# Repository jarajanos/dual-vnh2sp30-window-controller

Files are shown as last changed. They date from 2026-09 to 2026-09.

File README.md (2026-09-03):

# Window Controller — ESP32-C3 + Monster Moto Shield VNH2SP30

ESP-IDF firmware for controlling two motorized greenhouse windows. Each motor
supports one-button operation, MQTT commands, current monitoring, automatic
end-stop detection, and a movement timeout.

## Requirements

- ESP-IDF v6.x
- Target: `esp32c3`

## Build and flash

```bash
idf.py set-target esp32c3
idf.py menuconfig          # Optional; sdkconfig.defaults provides the defaults
idf.py build
idf.py -p /dev/ttyUSB0 flash monitor
```

## Configuration

Create your local configuration from the tracked template, then set at least
the Wi-Fi and MQTT credentials:

```bash
cp main/config.example.h main/config.h
```

Edit `main/config.h`:

```c
#define WIFI_SSID        "YourNetwork"
#define WIFI_PASSWORD    "YourPassword"
#define MQTT_BROKER_URI  "mqtt://192.168.1.100:1883"
```

GPIO mapping and shared defaults are configured in the same file. The local
`main/config.h` is ignored by Git so credentials are not committed; update
`main/config.example.h` when adding shared configuration options.

Each motor has independent startup defaults (`MOTOR1_*` and `MOTOR2_*`) for PWM,
movement timeout, overcurrent detection, and end-stop detection. Saved values
in NVS take precedence over these defaults.

## Web configuration

After connecting to Wi-Fi, open the IP address printed in the serial log, for
example `http://192.168.1.123/`. The page edits and validates both motor
configurations independently and stores them in NVS, so they survive a restart
or firmware update. A motor which is already moving finishes that movement with
its previous configuration; new values apply when the motor starts again.

The JSON representation is available at `GET /api/config`. The web UI saves
through `POST /api/config` using URL-encoded fields. The server listens on
`WEB_CONFIG_PORT` (80 by default) and currently has no authentication, so it
should only be exposed on a trusted local network.

Accepted per-motor ranges:

| Field | Range |
|---|---:|
| `pwm_duty` | 1–255 |
| `timeout_ms` | 100–3,600,000 ms |
| `overcurrent_min_run_ms` | 0–`timeout_ms` |
| `overcurrent_min_raw` | 0–4095 |
| `overcurrent_percent` | 101–1000% |
| `overcurrent_count` | 1–255 samples |
| `endstop_min_run_ms` | 0–`timeout_ms` |
| `endstop_min_raw` | 0–4095 |
| `endstop_drop_percent` | 1–99% |
| `endstop_count` | 1–255 samples |

## Window state machine

Each motor uses the following states:

- `unknown` — position is not known after startup
- `opening` — motor is opening the window
- `opened` — opening end stop was detected
- `closing` — motor is closing the window
- `closed` — closing end stop was detected
- `stopped` — movement was interrupted before reaching an end stop

A switch press performs an action based on the current state:

| Current state | Action |
|---|---|
| `unknown` or `closed` | Start opening |
| `opened` | Start closing |
| `opening` or `closing` | Stop |
| `stopped` | Move in the direction opposite to the previous movement |

Switch release does not trigger an action.

## Current monitoring

The VNH2SP30 current-sense output is sampled through the ESP32-C3 ADC. Four ADC
samples are averaged for each reading, and readings are taken every 50 ms.

The controller maintains an exponential moving average:

```text
new_average = (old_average * 7 + current_sample) / 8
```

Current monitoring starts after a 500 ms startup delay so the motor startup
surge does not trigger protection.

### Overcurrent detection

An overcurrent condition is detected when the measured current exceeds the
moving average by 10% for two consecutive readings. The motor is actively
braked and an MQTT alarm with reason `overcurrent` is published.

Relevant per-motor settings (shown for motor 1):

```c
#define MOTOR1_OVERCURRENT_MIN_RUN_MS  500
#define MOTOR1_OVERCURRENT_MIN_RAW     5
#define MOTOR1_OVERCURRENT_PERCENT     110
#define MOTOR1_OVERCURRENT_COUNT       2
#define CS_AVERAGE_HISTORY_WEIGHT  7
```

### End-stop detection

A mechanical end stop is recognized by a sharp current drop. When the measured
current falls to 45% or less of the moving average for three consecutive
readings, the motor is actively braked and its state changes to `opened` or
`closed`, depending on its direction.

Relevant per-motor settings (shown for motor 1):

```c
#define MOTOR1_ENDSTOP_MIN_RUN_MS    500
#define MOTOR1_ENDSTOP_MIN_RAW       5
#define MOTOR1_ENDSTOP_DROP_PERCENT  45
#define MOTOR1_ENDSTOP_COUNT         3
```

Both current thresholds should be tuned using measurements from the actual
motor and mechanism.

## Project structure

```text
window-esp-idf/
├── CMakeLists.txt
├── sdkconfig.defaults
└── main/
    ├── CMakeLists.txt
    ├── config.example.h  # Tracked configuration template
    ├── config.h          # Local configuration ignored by Git
    ├── main.c            # app_main, tasks, and orchestration
    ├── motor.h / .c      # Motor control, state machine, and protection
    ├── switch.h / .c     # Active-low switch debounce
    ├── wifi.h / .c       # Wi-Fi station initialization
    ├── mqtt.h / .c       # esp-mqtt wrapper with LWT support
    ├── settings.h / .c   # Per-motor NVS persistence
    └── web_config.h / .c # HTTP configuration UI and API
```

## GPIO map

| GPIO | Function | Description |
|---:|---|---|
| 0 | CS2 | ADC1_CH0 — Motor 2 current sense |
| 1 | CS1 | ADC1_CH1 — Motor 1 current sense |
| 3 | PWM2 | LEDC channel 1 — Motor 2 |
| 4 | INA2 | Motor 2 direction |
| 5 | INA1 | Motor 1 direction |
| 6 | INB1 | Motor 1 direction |
| 7 | INB2 | Motor 2 direction |
| 10 | PWM1 | LEDC channel 0 — Motor 1 |
| 18 | SW1 | Motor 1 switch, active-low with pull-up |
| 19 | SW2 | Motor 2 switch, active-low with pull-up |

## MQTT

### Commands

Commands use QoS 1. Accepted payloads are `open`, `close`, and `stop`.

| Topic | Target |
|---|---|
| `home/greenhouse/window/motor1/cmd` | Motor 1 |
| `home/greenhouse/window/motor2/cmd` | Motor 2 |
| `home/greenhouse/window/all/cmd` | Both motors |

### State

State messages use QoS 1 and are retained. The payload is the state name as a
plain string, for example:

```text
Topic:   home/greenhouse/window/motor1/state
Payload: opening
```

### Alarm

Alarms are published for overcurrent and timeout stops:

```json
{
  "motor": "Motor1",
  "reason": "overcurrent",
  "cs_raw": 24,
  "cs_avg_raw": 20,
  "current_A": 7.29
}
```

### Diagnostics

Diagnostics are published every 10 seconds to
`home/greenhouse/window/diag`:

```json
{
  "online": true,
  "uptime_s": 3600,
  "motor1": "closed",
  "motor2": "opening",
  "cs1_raw": 0,
  "cs2_raw": 18,
  "cs1_avg": 20,
  "cs2_avg": 17,
  "i1_A": 0.00,
  "i2_A": 5.47
}
```

### Last will and testament

| Topic | Payload | Published when |
|---|---|---|
| `home/greenhouse/window/status` | `online` | The controller connects to the broker |
| `home/greenhouse/window/status` | `offline` | The broker detects an unexpected disconnect |

## Safety mechanisms

| Mechanism | Configuration | Behavior |
|---|---|---|
| Relative overcurrent | `MOTOR1/2_OVERCURRENT_*` or web UI | Active brake and alarm after a configured excess |
| End-stop detection | `MOTOR1/2_ENDSTOP_*` or web UI | Active brake and final window state after a configured drop |
| Movement timeout | `MOTOR1/2_TIMEOUT_MS` or web UI | Active brake and alarm after the configured time |
| Active brake | INA=INB=LOW, PWM=0 | Stops the motor instead of coasting |
| Switch debounce | `SW_DEBOUNCE_MS=50` | Suppresses mechanical switch bounce |
| MQTT LWT | `TOPIC_LWT` | Reports an unexpected power or connection loss |

## Home Assistant example

```yaml
mqtt:
  button:
    - name: "Open window 1"
      command_topic: "home/greenhouse/window/motor1/cmd"
      payload_press: "open"
    - name: "Close window 1"
      command_topic: "home/greenhouse/window/motor1/cmd"
      payload_press: "close"

  sensor:
    - name: "Window 1 state"
      state_topic: "home/greenhouse/window/motor1/state"

  binary_sensor:
    - name: "Window controller"
      state_topic: "home/greenhouse/window/status"
      payload_on: "online"
      payload_off: "offline"
      device_class: connectivity
```

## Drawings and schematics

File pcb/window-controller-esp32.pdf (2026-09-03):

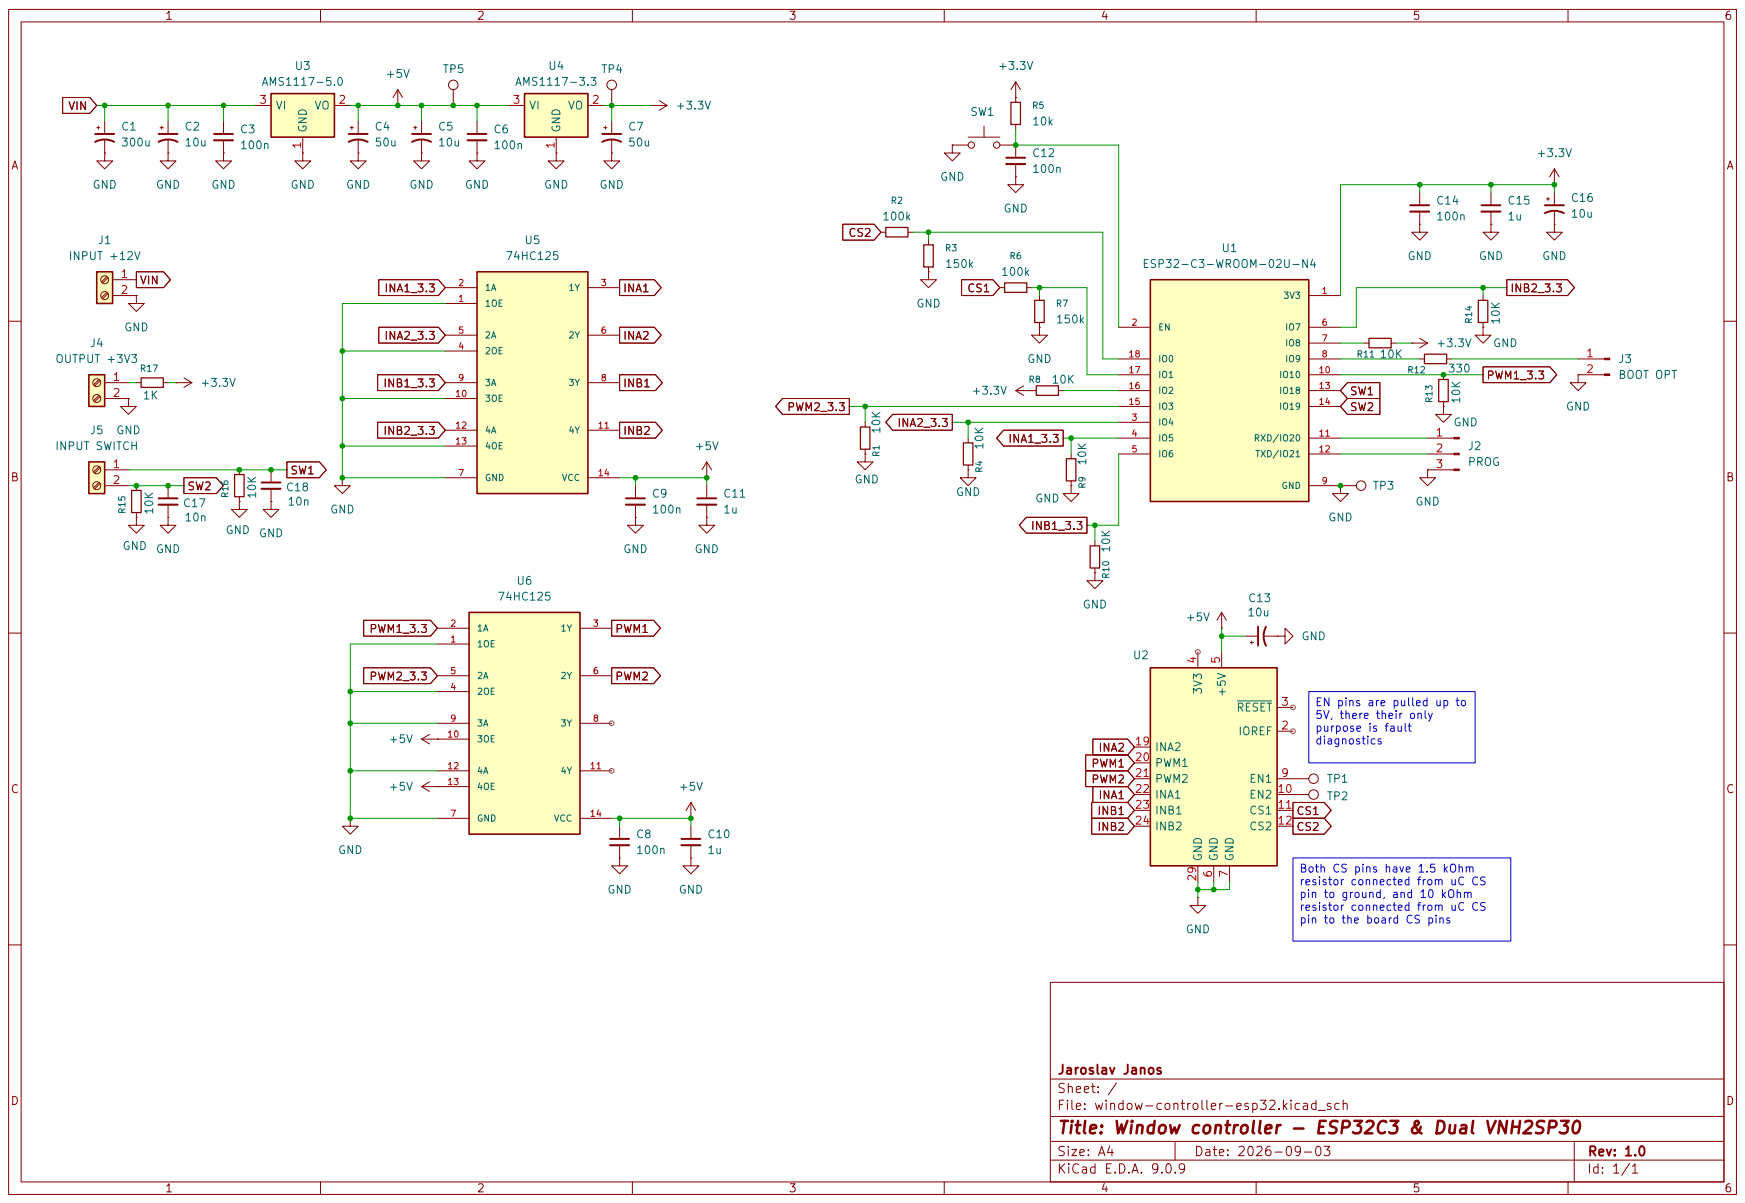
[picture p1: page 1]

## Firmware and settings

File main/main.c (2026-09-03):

#include <stdio.h>
#include <string.h>

#include "freertos/FreeRTOS.h"
#include "freertos/task.h"
#include "driver/ledc.h"
#include "esp_log.h"

#include "config.h"
#include "motor.h"
#include "switch.h"
#include "wifi.h"
#include "mqtt.h"
#include "settings.h"
#include "web_config.h"

static const char *TAG = "MAIN";

// ─── Motors ───────────────────────────────────────────────────────────────────

static motor_t motor1 = {
    .name       = "Motor1",
    .pin_ina    = PIN_INA1,
    .pin_inb    = PIN_INB1,
    .pin_cs     = PIN_CS1,
    .cs_channel = ADC_CHANNEL_1,   // GPIO1 = ADC1_CH1 on ESP32-C3
    .cs_unit    = ADC_UNIT_1,
    .ledc_ch    = LEDC_CH_M1,
    .config = {
        .pwm_duty = MOTOR1_PWM_DUTY,
        .timeout_ms = MOTOR1_TIMEOUT_MS,
        .overcurrent_min_run_ms = MOTOR1_OVERCURRENT_MIN_RUN_MS,
        .overcurrent_min_raw = MOTOR1_OVERCURRENT_MIN_RAW,
        .overcurrent_percent = MOTOR1_OVERCURRENT_PERCENT,
        .overcurrent_count = MOTOR1_OVERCURRENT_COUNT,
        .endstop_min_run_ms = MOTOR1_ENDSTOP_MIN_RUN_MS,
        .endstop_min_raw = MOTOR1_ENDSTOP_MIN_RAW,
        .endstop_drop_percent = MOTOR1_ENDSTOP_DROP_PERCENT,
        .endstop_count = MOTOR1_ENDSTOP_COUNT,
    },
};

static motor_t motor2 = {
    .name       = "Motor2",
    .pin_ina    = PIN_INA2,
    .pin_inb    = PIN_INB2,
    .pin_cs     = PIN_CS2,
    .cs_channel = ADC_CHANNEL_0,   // GPIO0 = ADC1_CH0 on ESP32-C3
    .cs_unit    = ADC_UNIT_1,
    .ledc_ch    = LEDC_CH_M2,
    .config = {
        .pwm_duty = MOTOR2_PWM_DUTY,
        .timeout_ms = MOTOR2_TIMEOUT_MS,
        .overcurrent_min_run_ms = MOTOR2_OVERCURRENT_MIN_RUN_MS,
        .overcurrent_min_raw = MOTOR2_OVERCURRENT_MIN_RAW,
        .overcurrent_percent = MOTOR2_OVERCURRENT_PERCENT,
        .overcurrent_count = MOTOR2_OVERCURRENT_COUNT,
        .endstop_min_run_ms = MOTOR2_ENDSTOP_MIN_RUN_MS,
        .endstop_min_raw = MOTOR2_ENDSTOP_MIN_RAW,
        .endstop_drop_percent = MOTOR2_ENDSTOP_DROP_PERCENT,
        .endstop_count = MOTOR2_ENDSTOP_COUNT,
    },
};

// ─── Switches ─────────────────────────────────────────────────────────────────

static switch_t sw1, sw2;

// One press opens, stops, or closes the window based on its current state.
static void sw1_cb(bool pressed, void *arg) {
    if (pressed) motor_toggle(&motor1);
}

static void sw2_cb(bool pressed, void *arg) {
    if (pressed) motor_toggle(&motor2);
}

// ─── JSON helpers ─────────────────────────────────────────────────────────────

static void build_alarm_json(motor_t *m, char *buf, size_t size) {
    snprintf(buf, size,
             "{\"motor\":\"%s\",\"reason\":\"%s\",\"cs_raw\":%d,"
             "\"cs_avg_raw\":%d,\"current_A\":%.2f}",
             m->name,
             motor_stop_reason_name(m->stop_reason),
             m->cs_raw,
             m->cs_average_raw,
             motor_current_a(m));
}

static void build_diag_json(char *buf, size_t size) {
    snprintf(buf, size,
             "{\"online\":true,\"uptime_s\":%lu,"
             "\"motor1\":\"%s\",\"motor2\":\"%s\","
             "\"cs1_raw\":%d,\"cs2_raw\":%d,"
             "\"cs1_avg\":%d,\"cs2_avg\":%d,"
             "\"i1_A\":%.2f,\"i2_A\":%.2f}",
             (unsigned long)(xTaskGetTickCount() * portTICK_PERIOD_MS / 1000),
             motor_state_name(motor1.state),
             motor_state_name(motor2.state),
             motor1.cs_raw, motor2.cs_raw,
             motor1.cs_average_raw, motor2.cs_average_raw,
             motor_current_a(&motor1),
             motor_current_a(&motor2));
}

// ─── MQTT command callback ────────────────────────────────────────────────────

static void on_mqtt_cmd(int idx, const char *cmd) {
    // Normalize the command to lowercase. Whitespace is not accepted.
    char c[16] = {};
    strncpy(c, cmd, sizeof(c) - 1);
    for (int i = 0; c[i]; i++) {
        if (c[i] >= 'A' && c[i] <= 'Z') c[i] += 32;
    }

    motor_t *targets[2] = { NULL, NULL };
    int n = 0;

    if      (idx == 0) { targets[0] = &motor1; n = 1; }
    else if (idx == 1) { targets[0] = &motor2; n = 1; }
    else               { targets[0] = &motor1; targets[1] = &motor2; n = 2; }

    for (int i = 0; i < n; i++) {
        motor_t *m = targets[i];
        if      (strcmp(c, "open")  == 0) motor_open(m);
        else if (strcmp(c, "close") == 0) motor_close(m);
        else if (strcmp(c, "stop")  == 0) motor_stop(m, STOP_REASON_COMMAND);
        else ESP_LOGW(TAG, "Unknown command: \"%s\"", cmd);
    }
}

// ─── FreeRTOS tasks ───────────────────────────────────────────────────────────

// Motor update loop, switch polling, and state publishing
static void motor_task(void *arg) {
    char json[192];
    TickType_t last_diag = xTaskGetTickCount();

    while (1) {
        // Debounce switches
        switch_update(&sw1);
        switch_update(&sw2);

        // Motor timeout and current-sense protection
        motor_update(&motor1);
        motor_update(&motor2);

        // Motor 1 state changed
        if (motor_take_state_changed(&motor1)) {
            const char* state = motor_state_name(motor1.state);
            mqtt_publish_state(0, state);
        }
        if (motor_take_alarm(&motor1)) {
            build_alarm_json(&motor1, json, sizeof(json));
            mqtt_publish_alarm(0, json);
        }

        // Motor 2 state changed
        if (motor_take_state_changed(&motor2)) {
            const char* state = motor_state_name(motor2.state);
            mqtt_publish_state(1, state);
        }
        if (motor_take_alarm(&motor2)) {
            build_alarm_json(&motor2, json, sizeof(json));
            mqtt_publish_alarm(1, json);
        }

        // Diagnostics
        if ((xTaskGetTickCount() - last_diag) * portTICK_PERIOD_MS >= DIAG_INTERVAL_MS) {
            last_diag = xTaskGetTickCount();
            build_diag_json(json, sizeof(json));
            mqtt_publish_diag(json);
        }

        vTaskDelay(pdMS_TO_TICKS(10));
    }
}

// ─── LEDC timer shared by both channels ──────────────────────────────────────

static void ledc_timer_init(void) {
    ledc_timer_config_t timer = {
        .speed_mode      = LEDC_MODE,
        .timer_num       = LEDC_TIMER,
        .duty_resolution = LEDC_DUTY_BITS,
        .freq_hz         = LEDC_FREQ_HZ,
        .clk_cfg         = LEDC_AUTO_CLK,
    };
    ESP_ERROR_CHECK(ledc_timer_config(&timer));

    // Motor 1 channel
    ledc_channel_config_t ch1 = {
        .gpio_num   = PIN_PWM1,
        .speed_mode = LEDC_MODE,
        .channel    = LEDC_CH_M1,
        .timer_sel  = LEDC_TIMER,
        .duty       = 0,
        .hpoint     = 0,
    };
    ESP_ERROR_CHECK(ledc_channel_config(&ch1));

    // Motor 2 channel
    ledc_channel_config_t ch2 = {
        .gpio_num   = PIN_PWM2,
        .speed_mode = LEDC_MODE,
        .channel    = LEDC_CH_M2,
        .timer_sel  = LEDC_TIMER,
        .duty       = 0,
        .hpoint     = 0,
    };
    ESP_ERROR_CHECK(ledc_channel_config(&ch2));
}

// ─── app_main ─────────────────────────────────────────────────────────────────

void app_main(void) {
    ESP_LOGI(TAG, "╔══════════════════════════╗");
    ESP_LOGI(TAG, "║  Window Controller v1.0  ║");
    ESP_LOGI(TAG, "╚══════════════════════════╝");

    // 1) NVS and persisted per-motor settings
    ESP_ERROR_CHECK(settings_init());
    motor_config_t loaded;
    ESP_ERROR_CHECK(settings_load_motor(0, &motor1.config, &loaded));
    motor_set_config(&motor1, &loaded);
    ESP_ERROR_CHECK(settings_load_motor(1, &motor2.config, &loaded));
    motor_set_config(&motor2, &loaded);

    // 2) Shared LEDC timer
    ledc_timer_init();

    // 3) Motors
    motor_init(&motor1);
    motor_init(&motor2);

    // 4) Switches
    switch_init(&sw1, PIN_SW1, sw1_cb, NULL);
    switch_init(&sw2, PIN_SW2, sw2_cb, NULL);

    // 5) Wi-Fi (blocks until an IP address is assigned)
    bool wifi_connected = wifi_init_sta() == ESP_OK;
    if (!wifi_connected) {
        ESP_LOGW(TAG, "Wi-Fi unavailable — MQTT and configuration UI will not work");
    }

    // 6) MQTT (esp-mqtt handles reconnection internally)
    ESP_ERROR_CHECK(mqtt_init(on_mqtt_cmd));

    // 7) Configuration UI on the device IP address
    if (wifi_connected) {
        esp_err_t err = web_config_start(&motor1, &motor2);
        if (err != ESP_OK) {
            ESP_LOGE(TAG, "Could not start configuration UI: %s", esp_err_to_name(err));
        }
    }

    // 8) Motor task with its own stack and a priority above IDLE
    xTaskCreate(motor_task, "motor_task", 4096, NULL, 5, NULL);

    ESP_LOGI(TAG, "System started.");
}

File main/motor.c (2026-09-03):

#include "motor.h"
#include "config.h"

#include "freertos/FreeRTOS.h"
#include "freertos/task.h"
#include "esp_log.h"

static const char *TAG = "MOTOR";

static adc_oneshot_unit_handle_t adc1_handle = NULL;
static portMUX_TYPE s_config_mux = portMUX_INITIALIZER_UNLOCKED;

// ─── Internal helpers ─────────────────────────────────────────────────────────

static void set_pins(motor_t *m, int ina, int inb, uint32_t duty) {
    gpio_set_level(m->pin_ina, ina);
    gpio_set_level(m->pin_inb, inb);
    ledc_set_duty(LEDC_MODE, m->ledc_ch, duty);
    ledc_update_duty(LEDC_MODE, m->ledc_ch);
}

// Active brake: INA=LOW, INB=LOW, PWM=0
static void apply_brake(motor_t *m) {
    set_pins(m, 0, 0, 0);
}

static bool motor_is_moving(const motor_t *m) {
    return m->state == MOTOR_OPENING || m->state == MOTOR_CLOSING;
}

static void snapshot_config(motor_t *m) {
    taskENTER_CRITICAL(&s_config_mux);
    m->active_config = m->config;
    taskEXIT_CRITICAL(&s_config_mux);
}

static void finish_at_endstop(motor_t *m) {
    motor_state_t finished_state = m->state == MOTOR_OPENING
                                 ? MOTOR_OPENED
                                 : MOTOR_CLOSED;

    apply_brake(m);
    m->state         = finished_state;
    m->stop_reason   = STOP_REASON_ENDSTOP;
    m->state_changed = true;

    ESP_LOGI(TAG, "[%s] End position reached: %s", m->name,
             motor_state_name(finished_state));
}

// ─── Public API ───────────────────────────────────────────────────────────────

void motor_init(motor_t *m) {
    // Configure INA and INB as GPIO outputs
    gpio_config_t io = {
        .pin_bit_mask = (1ULL << m->pin_ina) | (1ULL << m->pin_inb),
        .mode         = GPIO_MODE_OUTPUT,
        .pull_up_en   = GPIO_PULLUP_DISABLE,
        .pull_down_en = GPIO_PULLDOWN_DISABLE,
        .intr_type    = GPIO_INTR_DISABLE,
    };
    ESP_ERROR_CHECK(gpio_config(&io));

    // ADC current-sense channel
    if (adc1_handle == NULL) {
        adc_oneshot_unit_init_cfg_t adc_init_config = {
            .unit_id  = ADC_UNIT_1,
            .ulp_mode = ADC_ULP_MODE_DISABLE,
        };

        ESP_ERROR_CHECK(
            adc_oneshot_new_unit(&adc_init_config, &adc1_handle)
        );
    }

    adc_oneshot_chan_cfg_t adc_channel_config = {
        .bitwidth = ADC_BITWIDTH_12,
        .atten    = ADC_ATTEN_DB_12,
    };

    ESP_ERROR_CHECK(
        adc_oneshot_config_channel(
            adc1_handle,
            m->cs_channel,
            &adc_channel_config
        )
    );

    // The LEDC channel uses the shared timer initialized in main.c
    apply_brake(m);
    m->state           = MOTOR_UNKNOWN;
    m->stop_reason     = STOP_REASON_NONE;
    m->cs_raw          = 0;
    m->cs_average_raw  = 0;
    m->last_motion     = MOTOR_UNKNOWN;
    m->endstop_count   = 0;
    m->state_changed   = false;
    m->alarm_pending   = false;

    ESP_LOGI(TAG, "[%s] initialized", m->name);
}

void motor_open(motor_t *m) {
    if (m->state == MOTOR_OPENING || m->state == MOTOR_OPENED) return;
    ESP_LOGI(TAG, "[%s] OPEN", m->name);
    snapshot_config(m);
    set_pins(m, 1, 0, m->active_config.pwm_duty);
    m->state             = MOTOR_OPENING;
    m->state_changed     = true;
    m->stop_reason       = STOP_REASON_NONE;
    m->start_tick        = xTaskGetTickCount();
    m->last_cs_tick      = m->start_tick;
    m->overcurrent_count = 0;
    m->endstop_count     = 0;
    m->cs_average_raw    = 0;
    m->last_motion       = MOTOR_OPENING;
}

void motor_close(motor_t *m) {
    if (m->state == MOTOR_CLOSING || m->state == MOTOR_CLOSED) return;
    ESP_LOGI(TAG, "[%s] CLOSE", m->name);
    snapshot_config(m);
    set_pins(m, 0, 1, m->active_config.pwm_duty);
    m->state             = MOTOR_CLOSING;
    m->state_changed     = true;
    m->stop_reason       = STOP_REASON_NONE;
    m->start_tick        = xTaskGetTickCount();
    m->last_cs_tick      = m->start_tick;
    m->overcurrent_count = 0;
    m->endstop_count     = 0;
    m->cs_average_raw    = 0;
    m->last_motion       = MOTOR_CLOSING;
}

void motor_stop(motor_t *m, stop_reason_t reason) {
    if (!motor_is_moving(m)) return;
    ESP_LOGW(TAG, "[%s] STOP — reason: %s", m->name, motor_stop_reason_name(reason));
    m->stop_reason = reason;
    if (reason == STOP_REASON_OVERCURRENT || reason == STOP_REASON_TIMEOUT) {
        m->alarm_pending = true;
    }
    apply_brake(m);
    m->state         = MOTOR_STOPPED;
    m->state_changed = true;
}

void motor_toggle(motor_t *m) {
    switch (m->state) {
        case MOTOR_OPENED:
            motor_close(m);
            break;
        case MOTOR_CLOSED:
            motor_open(m);
            break;
        case MOTOR_OPENING:
        case MOTOR_CLOSING:
            motor_stop(m, STOP_REASON_COMMAND);
            break;
        case MOTOR_STOPPED:
            // After a manual stop, the next press moves in the opposite direction.
            if (m->last_motion == MOTOR_OPENING) motor_close(m);
            else                                motor_open(m);
            break;
        case MOTOR_UNKNOWN:
        default:
            // Position is unknown after restart; the first end stop calibrates it.
            motor_open(m);
            break;
    }
}
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

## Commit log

2026-09-03 Added configuration per webserver, split parameters per motor to allow different motor models
2026-09-03 Added KiCad schematics & PCB
    [window-controller-esp32.kicad_pcb, window-controller-esp32.kicad_sch]
